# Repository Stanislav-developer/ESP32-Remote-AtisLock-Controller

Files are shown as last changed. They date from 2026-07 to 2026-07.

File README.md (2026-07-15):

<div align="center">

# 🔐 Remote-Door V1.0 <br> Native Ethernet Edition

**Контролер дистанційного керування електромеханічним замком Atis Lock <br> на базі ESP32-C3 + W5500 з нативним стеком lwIP**







Автор: **[Stanislav Turii](https://github.com/Stanislav-developer)** · YouTube: **[@TehnoMaisterna](https://www.youtube.com/@TehnoMaisterna)**

</div>

---

## 🎬 Відеоогляд проєкту

<div align="center">
  <a href="https://youtu.be/d5a214GUi08">
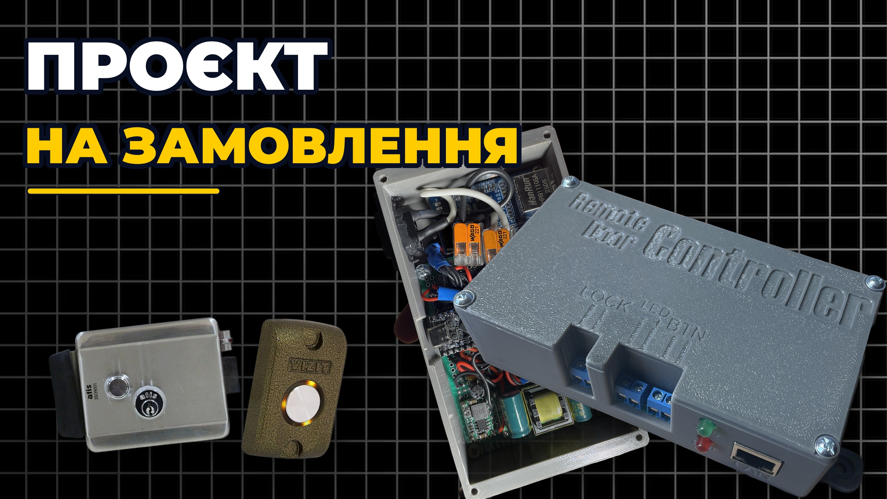
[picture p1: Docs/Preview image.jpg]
Відеоогляд Remote-Door V1.0
    
  </a>
  <p><i>▶️ Натисніть на зображення, щоб переглянути повний відеоогляд збірки та роботи пристрою</i></p>
</div>

---

## 📸 Готовий пристрій

<div align="center">
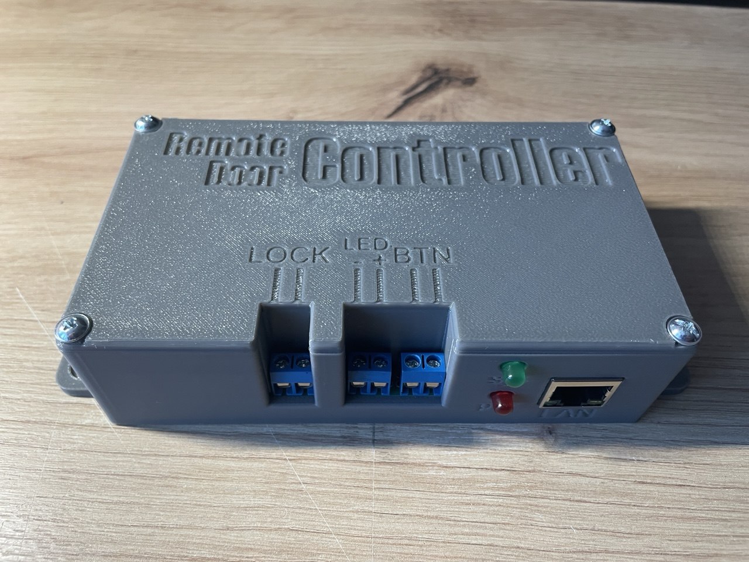
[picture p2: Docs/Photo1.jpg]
Remote-Door Controller — вигляд спереду
  
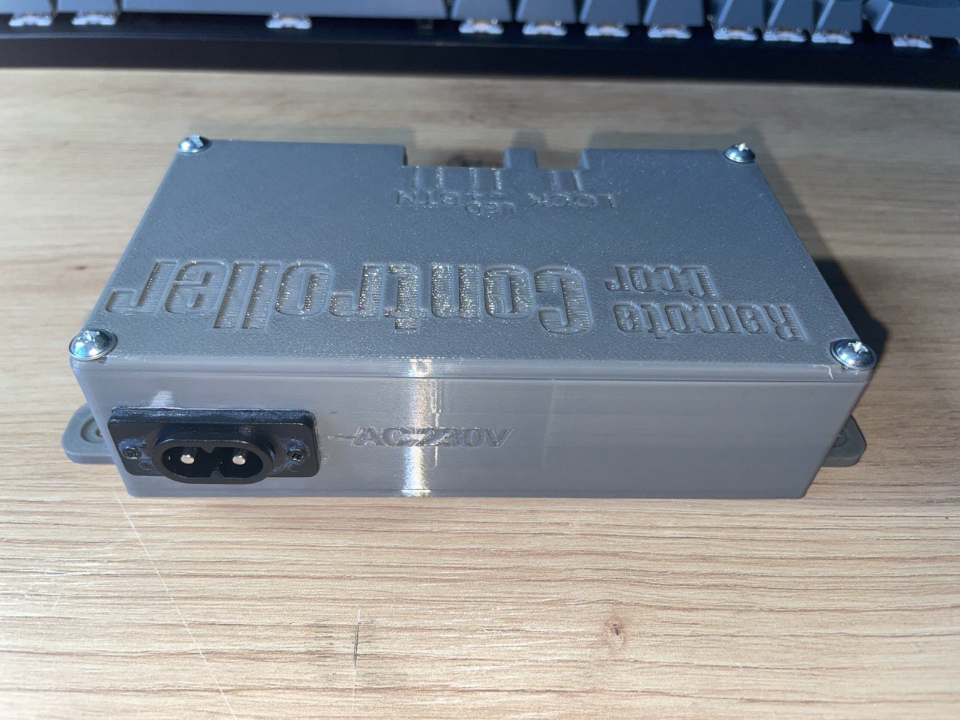
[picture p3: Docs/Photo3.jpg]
Remote-Door Controller — вигляд ззаду з роз'ємом живлення
  
  <br><br>
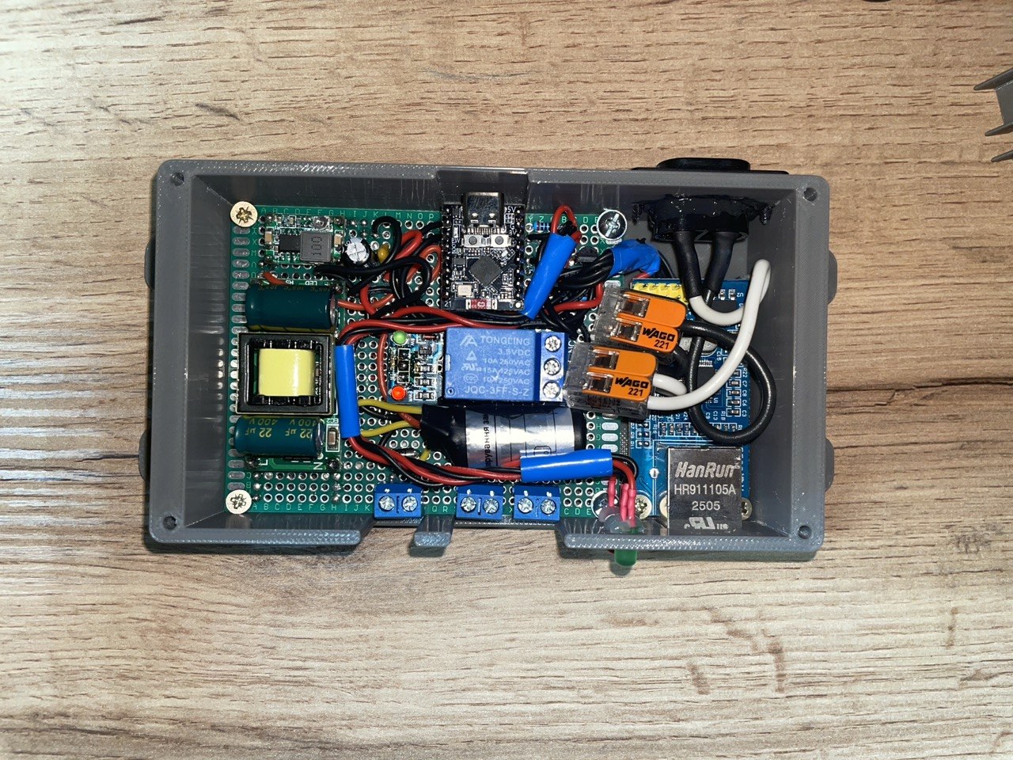
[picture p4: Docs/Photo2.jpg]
Внутрішня компоновка пристрою
  
  <p><i>Корпус надруковано на 3D-принтері. Внутрішня компоновка: AC-DC блок живлення, ESP32-C3, W5500, релейний модуль</i></p>
</div>

---

## 📖 Про проєкт

**Remote-Door** — це автономний контролер для дистанційного або локального керування електромеханічним замком (наприклад, **Atis Lock**) в укриттях, сховищах та об'єктах автоматизації.

Керування здійснюється двома шляхами:

- 🌐 **Дистанційно** — через Telegram-бота з будь-якої точки світу
- 🔘 **Локально** — фізичною антивандальною кнопкою виходу на стіні

Пристрій підключається до мережі **дротовим Ethernet** — жодних проблем з нестабільним Wi-Fi у бетонних укриттях та підвалах.

---

## ⚙️ Архітектура: чому Native Ethernet (ETH.h)?

Ключова особливість проєкту — модуль **W5500 монтується безпосередньо у внутрішній мережевий стек lwIP** операційної системи ESP32 через вбудовану бібліотеку `ETH.h`, а не через сторонні бібліотеки типу `Ethernet.h` чи `EthernetLarge`.

| Критерій | 🟢 Native `ETH.h` (lwIP) | 🔴 Сторонні бібліотеки |
|---|---|---|
| **Швидкість** | Максимальна — драйвер працює на рівні ядра | Програмна емуляція стека, повільніше |
| **DHCP** | Plug & Play, IP отримується автоматично | Часто потрібне ручне налаштування підмереж |
| **TLS / HTTPS** | Апаратне шифрування **mbedtls** — рідний `WiFiClientSecure` працює "з коробки" | Потрібні милиці типу SSLClient |
| **Фаєрволи провайдера** | Стабільне «пробиття» локальних провайдерських фаєрволів | Часті проблеми з NAT/фільтрацією |
| **Сумісність з екосистемою** | Весь код (Telegram, NTP, WebServer) працює як зі звичайним Wi-Fi | Кожна бібліотека вимагає адаптації під свій клієнт |

```cpp
// Монтування W5500 прямо у стек lwIP — одним рядком:
ETH.begin(ETH_PHY_W5500, 1, W5500_CS, -1, W5500_RST, SPI);
```

---

## ✨ Можливості (Features)

- 🤖 **Керування через Telegram** — відкриття замка, дозвіл/заборона кнопки, статус, скидання
- 🔘 **Фізична кнопка виходу** — антивандальна кнопка на стіні з керованою підсвіткою
- ⏳ **Захисний таймаут (Cooldown) 5 секунд** після кожного відкриття:
  - блокує заспамлювання командами з мережі
  - захищає котушку замка від перегріву
  - усуває брязкіт контактів кнопки
  - супроводжується асинхронним миготінням підсвітки кнопки
- 🌐 **Captive Portal конфігурації** — автономна точка доступу з веб-інтерфейсом для налаштування (пароль AP, Bot Token, Chat ID, Group ID). Запускається автоматично при чистій флеш-пам'яті або вручну кнопкою BOOT
- 🔑 **Дворівневе підтвердження безпеки** — команда `/clear_data` вимагає введення системного пароля перед очищенням пам'яті NVS
- 💡 **Асинхронна LED-індикація статусу (SYS LED)**:
  - ⚡ часте блимання — пошук DHCP / очікування мережі
  - 🌊 плавне ШІМ-«дихання» — режим веб-налаштування
  - 🔆 постійне світіння — стабільний зв'язок
- 📊 **Статистика** — лічильник відкривань та аптайм зберігаються у NVS
- 🕐 **Синхронізація часу** через NTP (`pool.ntp.org`, `time.google.com`)

---

## 📦 Специфікація компонентів (BOM)

### Основні модулі

| Фото | Компонент | Опис |
|:---:|---|---|
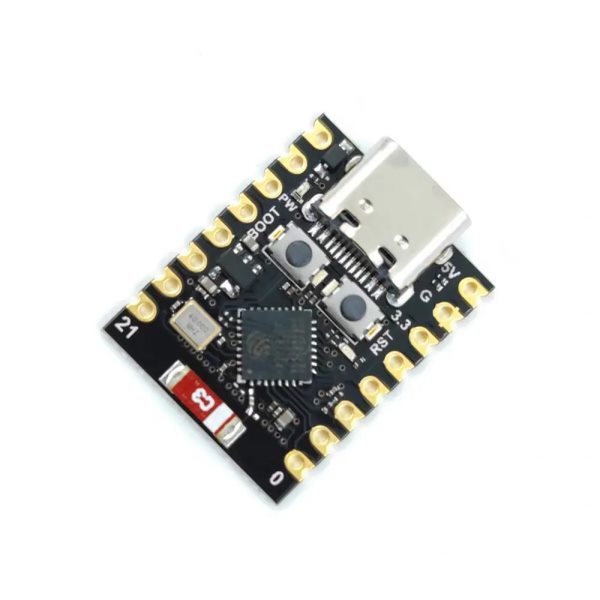
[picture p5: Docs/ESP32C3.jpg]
|  | **ESP32-C3 Super Mini** | Головний мікроконтролер (RISC-V, USB-C) |
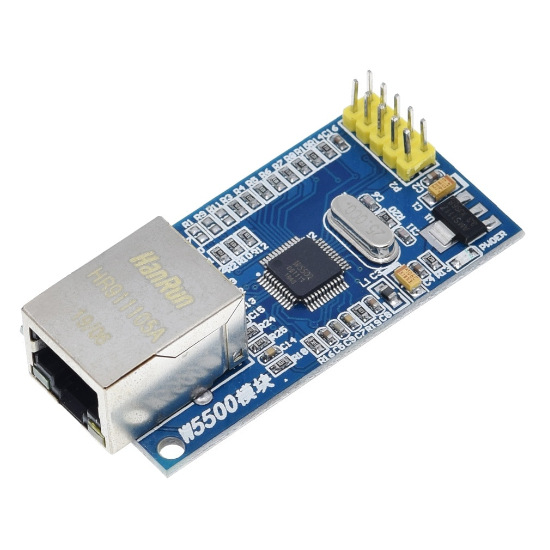
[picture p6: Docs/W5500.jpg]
|  | **W5500 Ethernet Module** | Апаратний TCP/IP контролер, SPI |
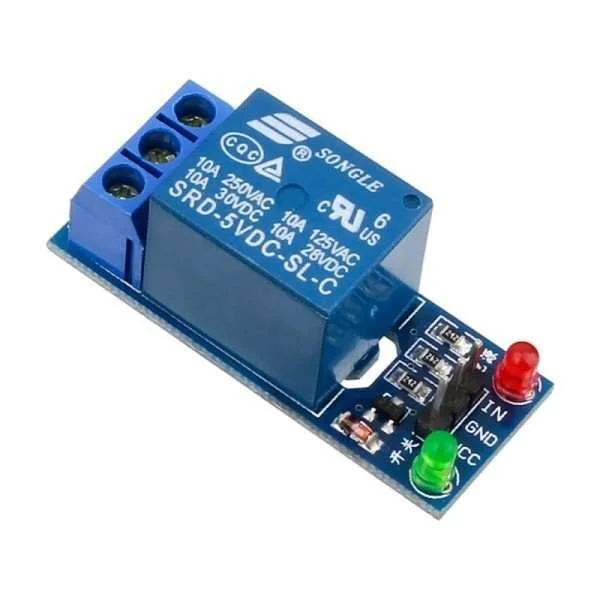
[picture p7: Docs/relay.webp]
|  | **Релейний модуль 5V** | Комутація живлення котушки замка (Active LOW) |
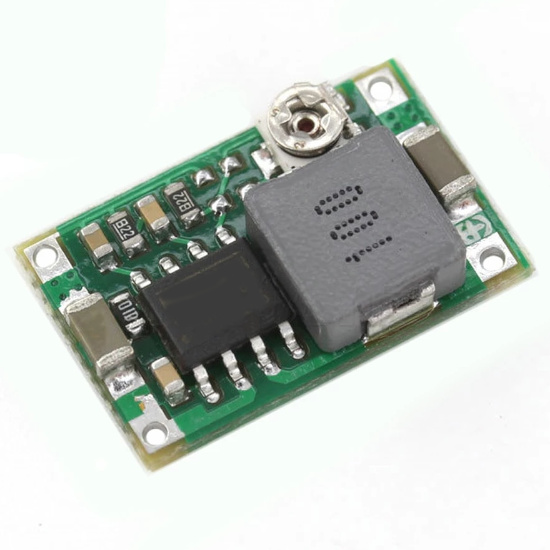
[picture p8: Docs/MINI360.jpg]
|  | **Mini360 (MP2307)** | DC-DC понижуючий конвертер 12V → 5V |
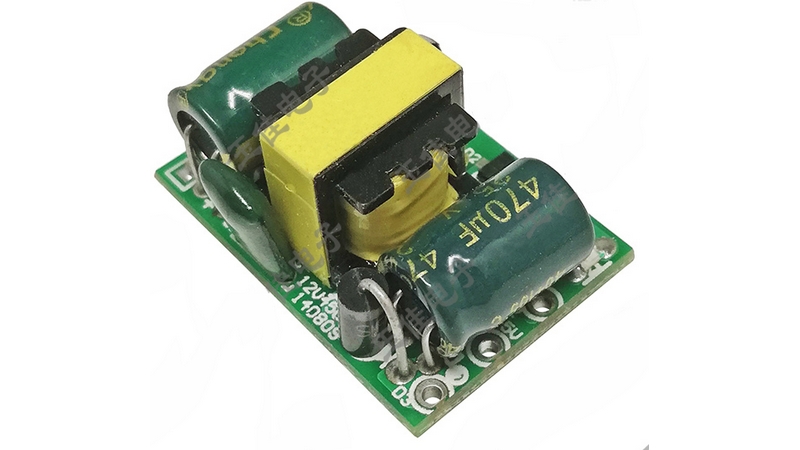
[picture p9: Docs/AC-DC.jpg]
|  | **AC-DC конвертер 220V → 12V, 1A** | Основне джерело живлення пристрою |
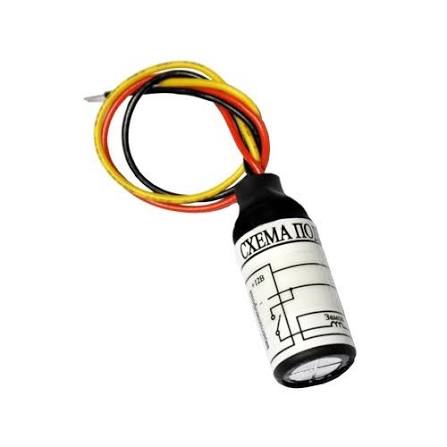
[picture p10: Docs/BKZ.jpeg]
|  | **БКЗ / БУЗ (Блок керування замком)** | Захист котушки замка та фільтрація завад |

### Дискретні компоненти та монтаж

| К-сть | Компонент | Призначення |
|:---:|---|---|
| 1 | Макетна плата **7×9 см** | Несуча плата для монтажу всіх модулів |
| 1 | Електролітичний конденсатор **47 мкФ** | Згладжування просідань живлення |
| 1 | Керамічний конденсатор **100 нФ (0.1 мкФ)** | Фільтрація ВЧ-завад по лінії 5V/GND |
| 2 | Світлодіоди **5 мм** | Індикація системного статусу (sys) та живлення (pwr) |
| 2 | Резистори **330 Ом** | Струмообмеження світлодіодів |
| 1 | Резистор **1.1 кОм** | База транзистора підсвітки кнопки |
| 1 | Резистор **10 кОм** | Підтяжка |
| 1 | Транзистор **BC547 (NPN)** | Ключ підсвітки кнопки виходу |
| 3 | Клеми **DG301-5.0-02P-12-02A** | Підключення замка (LOCK), підсвітки (LED), кнопки (BTN) |
| 1 | Гніздо **AC-006A** | Вхід мережевого живлення 220V |

---

## 🔌 Схема підключення

<div align="center">
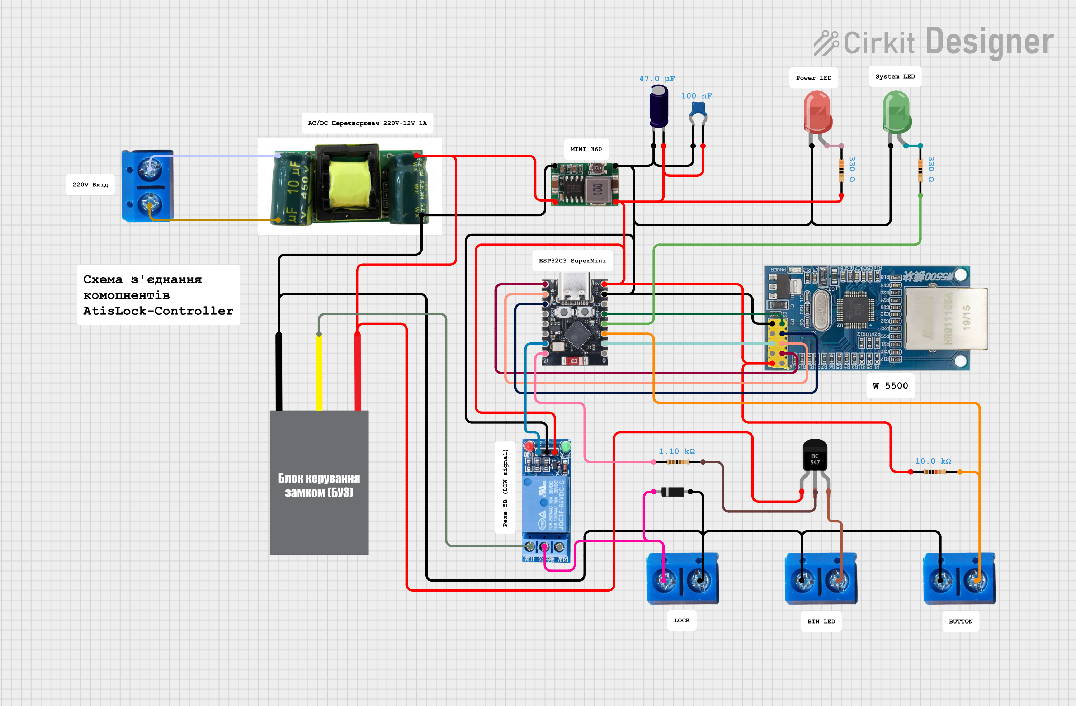
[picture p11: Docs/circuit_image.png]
Принципова схема Remote-Door V1.0
  
  <p><i>Повна схема з'єднань пристрою</i></p>
</div>

### Таблиця розпиновки (Pinout)

**ESP32-C3 ↔ W5500 (SPI):**

| Сигнал W5500 | GPIO ESP32-C3 |
|---|:---:|
| SCK | **4** |
| MISO | **5** |
| MOSI | **6** |
| CS | **7** |
| RST | **1** |

**Периферія:**

| Пристрій | GPIO | Режим |
|---|:---:|---|
| Реле замка | **20** | Active LOW, Z-стан у спокої |
| Транзистор підсвітки кнопки | **21** | Active HIGH |
| Кнопка виходу | **2** | `INPUT_PULLUP`, замикання на GND |
| Системний світлодіод (SYS LED) | **3** | ШІМ (LEDC, 1 кГц) |
| Кнопка BOOT (вхід у режим Setup) | **9** | `INPUT_PULLUP` |

### Транзисторний ключ підсвітки кнопки

Підсвітка реалізована за схемою **Active HIGH** через NPN-транзистор **BC547**:

```
GPIO21 ──[ R 1–1.5 кОм ]──► База BC547
                            Колектор ──► Катод LED кнопки (анод → +живлення)
                            Емітер   ──► GND
```

> [!WARNING]
> **Захист від завад — обов'язковий!** Пристрій працює поруч із силовим обладнанням. Для захисту від високочастотних завад електроінструменту (перфоратори, дрилі) та згладжування мікропросідань логіки живлення **обов'язково** встановіть:
> - **БКЗ (Блок Керування Замком)** у розрив лінії котушки замка
> - Керамічний конденсатор **0.1 мкФ** паралельно лініям живлення 5V/GND плат
> - Захисний діод **1N4007** на котушці замка (зворотним ввімкненням)
>
> Без цих елементів можливі хибні перезавантаження ESP32 у момент роботи замка.

> [!NOTE]
> Реле керується нестандартно, але безпечно: у стані спокою GPIO20 переведено у **високоімпедансний Z-стан** (`INPUT`), а для спрацювання пін короткочасно стає виходом із низьким рівнем. Це виключає випадкове відкриття замка при старті/перезавантаженні контролера.

---

## 🖨️ 3D-модель корпуса

Корпус розроблено у **Fusion 360** та надруковано на 3D-принтері. Кришка має гравіювання назви пристрою та маркування всіх клем (LOCK / LED / BTN), а бічні панелі — вирізи під RJ45, індикатори та гніздо живлення 230V.

<div align="center">
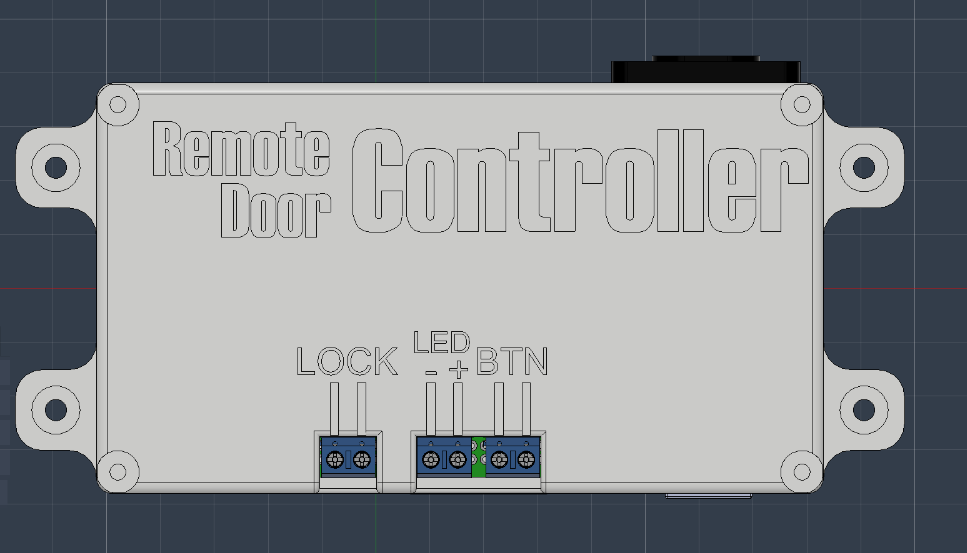
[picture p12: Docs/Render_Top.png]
Рендер верхньої кришки з маркуванням клем
  
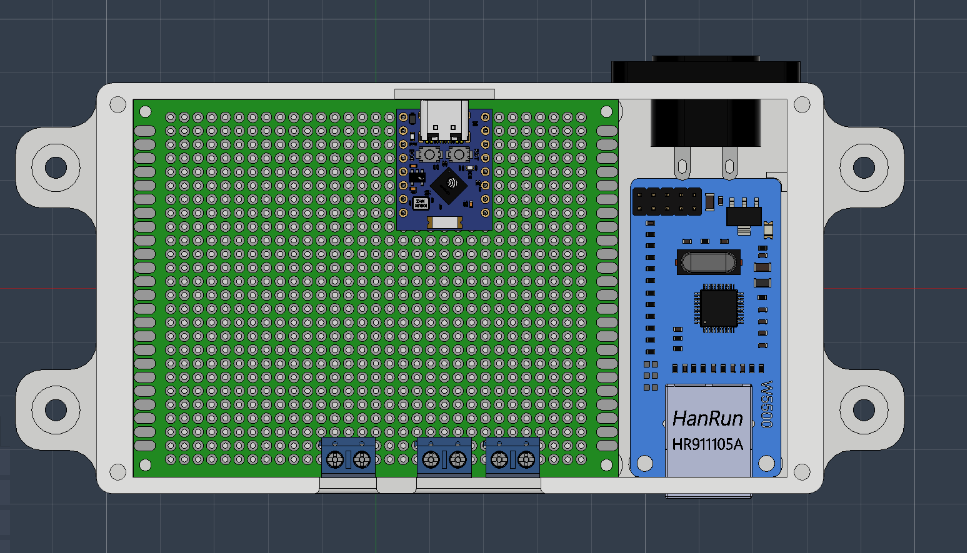
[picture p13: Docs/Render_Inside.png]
Рендер внутрішньої компоновки
  
  <br><br>
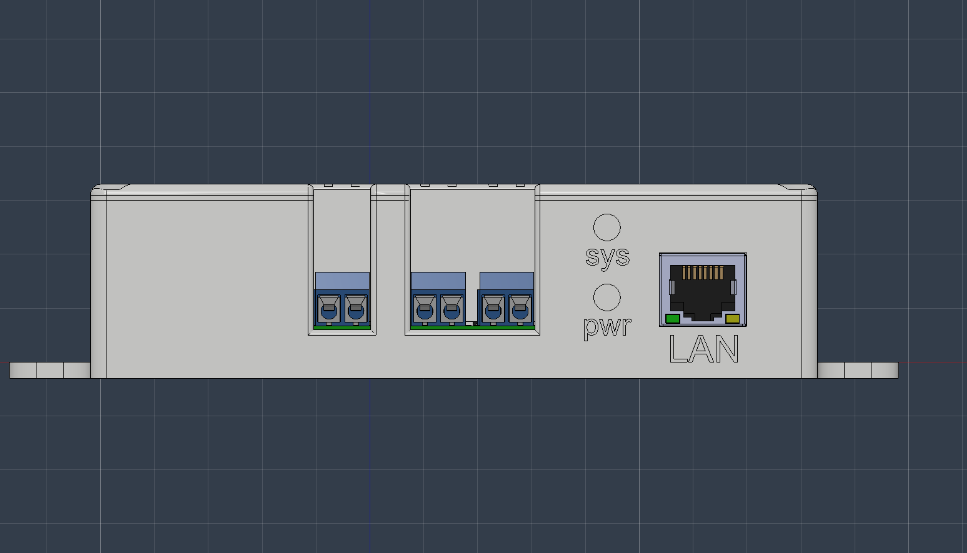
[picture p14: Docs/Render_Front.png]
Рендер передньої панелі: клеми, індикатори sys/pwr, LAN
  
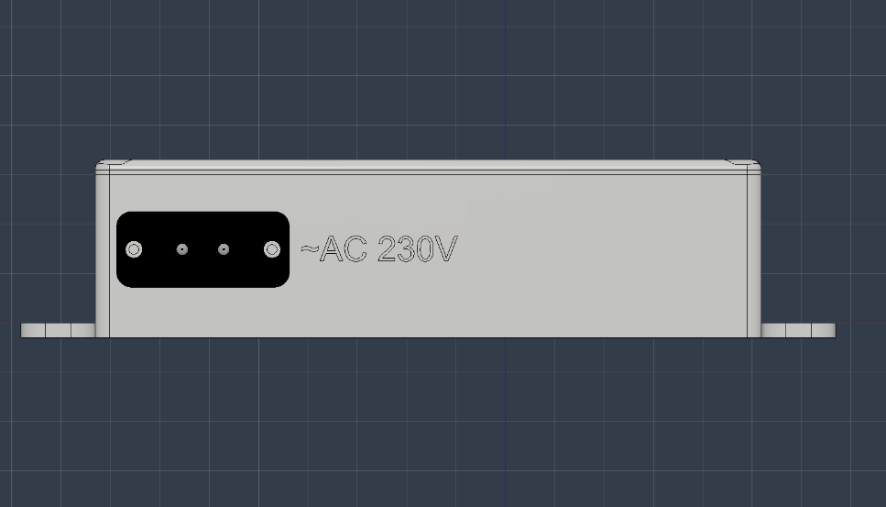
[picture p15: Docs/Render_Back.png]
Рендер задньої панелі: гніздо AC 230V
  
</div>

### 📥 Завантажити файли для друку

| Файл | Опис |
|---|---|
| [**Top.stl**](3D%20Models/Top.stl) | Верхня кришка з гравіюванням та отворами під клеми |
| [**Bottom.stl**](3D%20Models/Bottom.stl) | Основа корпуса з монтажними вушками |

> [!TIP]
> Рекомендовані налаштування друку: PETG або ABS (пристрій може працювати у неопалюваних приміщеннях), заповнення 15–20%, шар 0.2 мм.

---

## 🚀 Перший запуск та конфігурація

### Крок 1 — Прошивка

Налаштування **Arduino IDE** (меню *Tools*):

| Параметр | Значення |
|---|---|
| Board | `ESP32C3 Dev Module` |
| **USB CDC On Boot** | `Enabled` ⚠️ *(обов'язково для Serial Monitor)* |
| **Partition Scheme** | `Huge APP (3MB No OTA/1MB SPIFFS)` |
| Решта налаштувань | за замовчуванням |

Необхідна бібліотека: [`UniversalTelegramBot`](https://github.com/witnessmenow/Universal-Arduino-Telegram-Bot) (встановлюється через Library Manager).

**Вхід у режим прошивки (bootloader):**
1. Під'єднайте ESP32-C3 до комп'ютера через USB-C
2. Затисніть кнопку **BOOT**
3. Утримуючи BOOT, натисніть **RESET** (~1 сек)
4. Відпустіть RESET, потім відпустіть BOOT

### Крок 2 — Створення Telegram-бота

1. Напишіть [@BotFather](https://t.me/BotFather) → `/newbot` → отримайте **Bot Token**
2. Дізнайтеся свій **Chat ID** (наприклад, через [@userinfobot](https://t.me/userinfobot))
3. *(Опційно)* Додайте бота у групу та отримайте її **Group ID**

### Крок 3 — Налаштування через Web-інтерфейс

1. При **першому запуску** (чиста флеш-пам'ять) пристрій автоматично створює точку доступу **`Remote-Door-Setup`**. Системний світлодіод плавно «дихає» 🌊
2. Підключіться до цієї Wi-Fi мережі з телефона — Captive Portal відкриє сторінку налаштувань автоматично (або перейдіть на `192.168.4.1`)
3. Заповніть поля:
   - **Системний пароль** (мін. 8 символів) — захищає точку доступу та команду скидання
   - **Telegram Bot Token**
   - **Chat ID власника**
   - **Group ID** *(необов'язково)*
4. Натисніть **ЗБЕРЕГТИ** — пристрій перезавантажиться та підключиться до мережі

> [!TIP]
> Щоб **повторно увійти в режим налаштування** на вже сконфігурованому пристрої — затисніть кнопку **BOOT (GPIO9)** та увімкніть живлення (або натисніть RESET, утримуючи BOOT).

### Крок 4 — Підключення Ethernet

Вставте кабель у роз'єм RJ45 (LAN). Пристрій отримає IP через **DHCP** автоматично — жодних ручних налаштувань. Після успішного підключення:
- системний LED (sys) світиться **постійно** 🔆
- у Telegram надходить повідомлення *«Контролер Remote-Door активний!»*

---

## 🤖 Команди Telegram-бота

| Команда | Дія |
|---|---|
| `/unlock` | 🔓 Відчинити двері *(прихована з публічного меню)* |
| `/allow` | ✅ Дозволити відкриття з фізичної кнопки |
| `/deny` | 🚫 Заборонити відкриття з фізичної кнопки |
| `/status` | 📊 Статус системи, лічильник відкривань, аптайм |
| `/clear_data` | ⚠️ Повне скидання конфігурації *(вимагає пароль)* |
| `/help`, `/start` | 👋 Довідка |

### Список для швидкої вставки у BotFather (`/setcommands`)

```
allow - Дозволити відкриття дверей з фізичної кнопки
deny - Заборонити відкриття дверей з фізичної кнопки
status - Отримати статус системи та час аптайму
clear_data - Повне скидання конфігурації та статистики
```

> [!NOTE]
> Команда `/unlock` **свідомо не додається** у публічне меню бота — вона працює, але не світиться у списку команд. Це додатковий рівень захисту від випадкового натискання.

---

## 📁 Структура репозиторію

```
ESP32-Remote-AtisLock-Controller/
├── 3D Models/
│   ├── Top.stl                  # Верхня кришка корпуса
│   └── Bottom.stl               # Основа корпуса
├── Docs/                        # Фото, схема, рендери для README
├── Remote_Door_V1.0/
│   └── Remote_Door_V1.0.ino    # Прошивка
├── LICENSE                      # MIT
└── README.md
```

---

## 📜 Ліцензія

Проєкт розповсюджується за ліцензією **[MIT](LICENSE)** — використовуйте, модифікуйте та діліться вільно.

---

<div align="center">

**Developed with ❤️ by [Stanislav Turii](https://github.com/Stanislav-developer)**

🎥 [YouTube — TehnoMaisterna](https://www.youtube.com/@TehnoMaisterna) · 💻 [GitHub](https://github.com/Stanislav-developer)

⭐ *Якщо проєкт був корисним — поставте зірку репозиторію!*

</div>

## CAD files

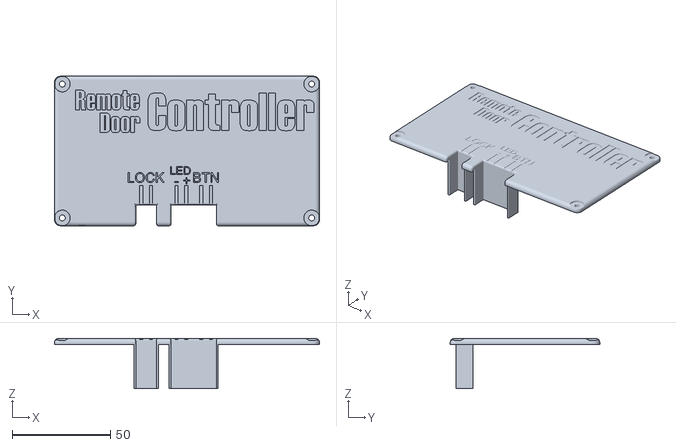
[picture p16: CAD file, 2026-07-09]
3D Models/Top.stl
135.0 x 76.2 x 25.5

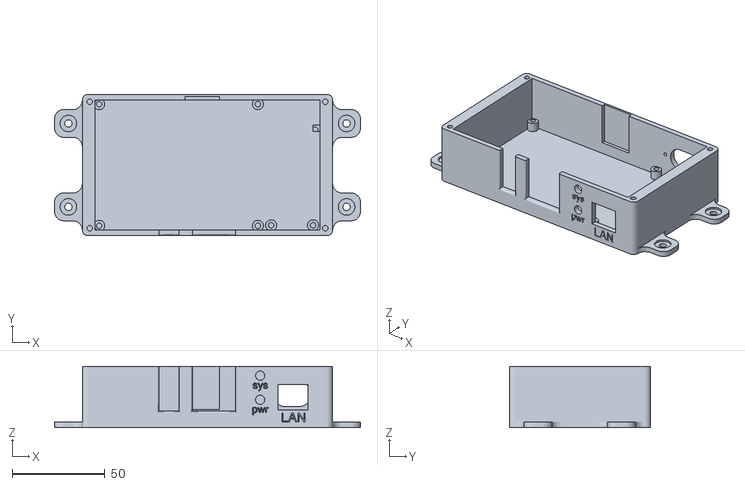
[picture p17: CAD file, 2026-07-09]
3D Models/Bottom.stl
165.0 x 76.2 x 33.0

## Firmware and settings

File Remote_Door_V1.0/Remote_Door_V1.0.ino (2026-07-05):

/* Remote-Door firmware V1.0
Repository: https://github.com/Stanislav-developer/ESP32-Remote-AtisLock-Controller
Author: Stanislav Turii (GitHub: https://github.com/Stanislav-developer || Youtube: https://www.youtube.com/@TehnoMaisterna)
Date: 2026.05.23

НАЛАШТУВАННЯ ДЛЯ ЗАЛИВКИ ПРОШИВКИ (ESP32-C3):
У Tools:
1. Board: "ESP32C3 Dev Module"
2. USB CDC On Boot: "Enabled" (Обов'язково для Serial Monitor)
3. Решта налаштувань: за замовчуванням

ЯК УВІЙТИ В РЕЖИМ ПРОШИВКИ:
1. Під'єднайте ESP32 до комп'ютера.
2. Затисніть кнопку BOOT.
3. Утримуючи BOOT, натисніть кнопку RESET (1 сек).
4. Відпустіть RESET, а потім відпустіть BOOT.
*/

// Підключення вбудованих бібліотек ядра ESP32
#include <ETH.h> // Для роботи з Ethernet залізом на рівні ядра
#include <SPI.h> // Для зв'язку з W5500 по SPI шині
#include <WiFi.h> // Потрібна для підняття власної точки доступу (AP)
#include <WiFiClientSecure.h> // Нативний захищений SSL клієнт
#include <WebServer.h> // Для роботи веб-сервера конфігурації
#include <DNSServer.h> // Для перенаправлення трафіку (Captive Portal)
#include <Preferences.h> // Для роботи з енергонезалежною пам'яттю
#include <UniversalTelegramBot.h> // Бібліотека Telegram API

// Конфігурація апаратних пінів (ESP32-C3 Super Mini)
#define RELAY_PIN 20     // Керування силовим реле замка (Активний низький)
#define LED_BTN_PIN 21   // Транзистор підсвітки кнопки (Активний високий)
#define BUTTON_PIN 2     // Домофонна кнопка виходу на стіні (INPUT_PULLUP)
#define LED_SYS_PIN 3    // Системний світлодіод індикації статусу (ШІМ сумісний)

// Апаратні піни SPI шини та скидання для Ethernet контролера W5500
#define W5500_SCK 4
#define W5500_MISO 5
#define W5500_MOSI 6
#define W5500_CS 7
#define W5500_RST 1

// Дані конфігурації системи (заповнюються через Веб-Інтерфейс або Preferences)
String apPassword = "";  // Пароль для точки доступу та скидання налаштувань
String botToken = "";    // API Токен Telegram бота
String chatId = "";      // Чат ID адміна (власника системи)
String groupId = "";     // Чат ID робочої групи або каналу

// Об'єкти системних класів
Preferences preferences; // Об'єкт для збереження конфігурації в NVS флеш
WiFiClientSecure client; // Безпечний клієнт із підтримкою апаратного mbedtls
UniversalTelegramBot bot(botToken, client); // Об'єкт обробника Telegram API
WebServer server(80);     // Веб-сервер на стандартному 80 порту
DNSServer dnsServer;     // DNS сервер для реалізації Captive Portal

// --- ГЛОБАЛЬНІ ЗМІННІ СТАНУ ---
bool isAccessAllowed = false; // Дозвіл на відкриття дверей з фізичної кнопки
int openCount = 0;            // Загальна кількість відкривань замка за весь час

// Змінні для асинхронного керування системним світлодіодом (без затримок delay)
unsigned long lastSysLedBlink = 0; // Таймер останнього перемикання стану LED
bool sysLedState = false;          // Поточний стан світлодіода (вкл/викл)
int sysLedInterval = 300; // Інтервал блимання: 300мс - пошук мережі, 1500мс - помилка, 0 - норма

// Змінні захисного таймауту кнопки та реле (блокування від заспамлювання)
bool isButtonCooldown = false;     // Прапорець активного режиму блокування
unsigned long cooldownStartTime = 0; // Час початку таймауту безпеки
unsigned long lastBtnLedToggle = 0; // Таймер миготіння підсвітки кнопки
bool btnLedState = false;          // Поточний стан підсвітки кнопки виходу
const unsigned long COOLDOWN_DURATION = 5000; // Тривалість блокування (5 секунд)

// Змінні авторизації для процедури очищення пам'яті через чат
bool waitingForClearDataPass = false; // Очікування введення пароля в чат
String clearDataRequesterId = "";     // ID користувача, який затребував очищення

// Глобальний прапор успішного підключення Ethernet на рівні lwIP стеку
bool eth_connected = false;

// HTML код розмітки сторінки конфігурації Веб-Інтерфейсу
const char index_html[] PROGMEM = R"rawliteral(
<!DOCTYPE HTML><html><head>
  <title>Remote-Door Setup</title>
  <meta charset="UTF-8">
  <meta name="viewport" content="width=device-width, initial-scale=1">
  <style>
    body { font-family: Arial, sans-serif; background-color: #0b132b; color: #ffffff; text-align: center; margin: 0; }
    .header { background-color: #1c2541; padding: 20px; border-bottom: 3px solid #3a506b; }
    .container { padding: 20px; max-width: 400px; margin: 0 auto; background-color: #1c2541; border-radius: 8px; margin-top: 20px; }
    input { width: 100%; padding: 12px; margin: 8px 0; box-sizing: border-box; background-color: #0b132b; color: #fff; border: 2px solid #3a506b; border-radius: 4px; }
    input[type=submit] { background-color: #3a506b; color: white; border: none; cursor: pointer; font-weight: bold; font-size: 16px; margin-top: 10px; }
    input[type=submit]:hover { background-color: #5bc0be; color: #0b132b; }
    .footer { margin-top: 30px; font-size: 12px; color: #aaa; border-top: 1px solid #3a506b; padding-top: 15px; }
    a { color: #5bc0be; text-decoration: none; display: block; margin-bottom: 10px; }
  </style>
</head><body>
  <div class="header"><h1>Remote-Door V1.0 (Ethernet)</h1></div>
  <div class="container">
    <h3>Налаштування пристрою</h3>
    <form action="/save" method="POST">
      <label>Системний пароль (для AP та скидання)</label><input type="text" name="ap_pass" placeholder="Мінімум 8 символів">
      <label>Telegram Bot Token</label><input type="text" name="token" placeholder="Токен бота">
      <label>Власник (Chat ID)</label><input type="text" name="owner" placeholder="ID власника">
      <label>Група (Group ID)</label><input type="text" name="group" placeholder="ID групи (необов'язково)">
      <input type="submit" value="ЗБЕРЕГТИ">
    </form>
    <div class="footer">
      <h4>Developed by Stanislav Turii</h4>
      <a href='https://github.com/Stanislav-developer'>GitHub Repository</a>
    </div>
  </div>
</body></html>)rawliteral";

// Функція відображення головної сторінки сервера
void handleRoot() {
  server.send(200, "text/html; charset=utf-8", index_html);
}

// Функція валідації та збереження отриманих даних у Preferences
void handleSave() {
  if (server.hasArg("token") && server.hasArg("owner") && server.hasArg("ap_pass")) {
    String n_token = server.arg("token");
    String n_owner = server.arg("owner");
    String n_group = server.arg("group");
    String n_ap_pass = server.arg("ap_pass");

    if (n_ap_pass.length() >= 8) {
      preferences.putString("token", n_token);
      preferences.putString("chatId", n_owner);
      preferences.putString("groupId", n_group);
      preferences.putString("apPass", n_ap_pass);

      String response = "<html><head><meta charset='utf-8'></head><body style='background-color:#0b132b; color:white; text-align:center; font-family:Arial;'>";
      response += "<h1 style='color:#5bc0be;'>Збережено! ✅</h1><p>Перезавантаження...</p></body></html>";
      server.send(200, "text/html; charset=utf-8", response);
      
      delay(2000);
      ESP.restart(); // Перезапуск для застосування конфігурації
    } else {
      server.send(400, "text/plain; charset=utf-8", "Помилка: Системний пароль має бути мінімум 8 символів!");
      return;
    }
  } else {
    server.send(400, "text/plain; charset=utf-8", "Error: Missing data");
  }
}

// Функція ініціалізації аварійної точки доступу та вічного циклу Веб-сервера
void launchWebServer() {
    WiFi.mode(WIFI_AP);
    if (apPassword.length() >= 8 && apPassword != "1") {
      WiFi.softAP("Remote-Door-Setup", apPassword.c_str());
    } else {
      WiFi.softAP("Remote-Door-Setup");
    }
    
    dnsServer.start(53, "*", WiFi.softAPIP());
    server.on("/", handleRoot);
    server.on("/save", handleSave);
    server.onNotFound(handleRoot);
    server.begin();
    
    Serial.println("[DEBUG] Точка доступу створена. IP: " + WiFi.softAPIP().toString());

    int fadeValue = 0;
    int fadeDirection = 5;
    unsigned long lastFadeTime = 0;

    // Вічний ізольований цикл обробки веб-запитів із плавним ШІМ ефектом для системного LED
    while (true) {
      dnsServer.processNextRequest();
      server.handleClient();
      
      if (millis() - lastFadeTime > 25) {
        lastFadeTime = millis();
        fadeValue += fadeDirection;
        if (fadeValue <= 0 || fadeValue >= 255) {
          fadeDirection = -fadeDirection; 
        }
        ledcWrite(LED_SYS_PIN, fadeValue);
      }
    }
}

// Конвертація лічильника секунд аптайму у текстовий формат (дні, години, хвилини)
String formatDuration(unsigned long seconds) {
  unsigned long days = seconds / 86400;
  unsigned long hours = (seconds % 86400) / 3600;
  unsigned long minutes = (seconds % 3600) / 60;
  unsigned long secs = seconds % 60;
  String result = "";
  if (days > 0) result += String(days) + " д. ";
  if (hours > 0 || days > 0) result += String(hours) + " год. ";
  if (minutes > 0 || hours > 0 || days > 0) result += String(minutes) + " хв. ";
  result += String(secs) + " сек.";
  return result;
}

// Функція генерації низькорівневого імпульсу на реле для відкриття замка
void openDoor() {
  digitalWrite(RELAY_PIN, LOW);   // Гарантуємо низький рівень (увімкнення реле)
  pinMode(RELAY_PIN, OUTPUT);     // Перемикаємо на вихід для подачі землі на реле
  delay(1000);                    // Утримання імпульсу 1 секунду (стандарт контролерів)
  pinMode(RELAY_PIN, INPUT);      // Переводимо у високоімпедансний стан (відпускаємо реле)
  
  openCount++;
  preferences.putInt("openCount", openCount);
  Serial.println("[DEBUG] Двері фізично відчинено (імпульс реле завершено).");
}

// Функція розбору та маршрутизації команд, що прийшли через мережу з серверів Telegram
void handleNewMessages() {
  String chat_id = String(bot.messages[0].chat_id);
  String text = bot.messages[0].text;
  String from_name = bot.messages[0].from_name;
  
  if (chat_id == chatId || chat_id == groupId) {
    
    // КРИТИЧНИЙ ЗАХИСТ: Ігноруємо порожні текстові об'єкти (медіафайли, стікери), запобігаючи паніці ядра
    if (text.length() == 0) return;

    // Очищення та нормалізація синтаксису команд (відрізання аргументів та тегів бота)
    String cmd = text;
    int spaceIdx = cmd.indexOf(' ');
    if (spaceIdx != -1) cmd = cmd.substring(0, spaceIdx); 
    int atIdx = cmd.indexOf('@');
    if (atIdx != -1) cmd = cmd.substring(0, atIdx);       

    // Обробка введення пароля для підтвердження процедури повного очищення флеш-пам'яті
    if (waitingForClearDataPass && chat_id == clearDataRequesterId) {
        if (text == apPassword && apPassword.length() > 0) {
            Serial.println("[DEBUG] Користувач [" + from_name + "] ввів ПРАВИЛЬНИЙ пароль. Очищення пам'яті NVS та рестарт.");
            preferences.clear();
            preferences.putString("token", "1");
            preferences.putString("chatId", "1");
            preferences.putString("groupId", "1");
            preferences.putString("apPass", "1");
            
            bot.sendMessage(chat_id, "⚠️ Дані очищені. Перезапуск у режим конфігурації...", "");
            delay(1000);
            ESP.restart(); 
        } else {
            Serial.println("[DEBUG] Користувач [" + from_name + "] ввів НЕВІРНИЙ пароль для очищення даних. Скасовано.");
            bot.sendMessage(chat_id, "❌ Невірний пароль. Операцію скасовано.", "");
            waitingForClearDataPass = false;
        }
        return; 
    }

    // Команда дистанційного відкриття дверей
    if (cmd == "/unlock") {
      if (isButtonCooldown) {
        unsigned long remaining = (COOLDOWN_DURATION - (millis() - cooldownStartTime)) / 1000;
        if (remaining == 0) remaining = 1;
        
        Serial.println("[DEBUG] Користувач [" + from_name + "] викликав /unlock під час таймауту. ВІДХИЛЕНО. Залишилось: " + String(remaining) + "с.");
        bot.sendMessage(chat_id, "⏳ <b>Зачекайте!</b> Замок щойно відчинявся. Тайм-аут: " + String(remaining) + " сек.", "HTML");
      } else {
        Serial.println("[DEBUG] Користувач [" + from_name + "] викликав /unlock. Виконую відкриття дверей...");
        bot.sendMessage(chat_id, "🔓 Користувач <b>" + from_name + "</b> відчинив двері.", "HTML");
        
        openDoor(); 
        
        isButtonCooldown = true;
        cooldownStartTime = millis(); // Старт таймауту безпеки строго після закриття реле
      }
    }
    
    // Команда активації локальної кнопки виходу
    else if (cmd == "/allow") {
      Serial.println("[DEBUG] Користувач [" + from_name + "] надіслав /allow. Доступ з кнопки дозволено.");
      isAccessAllowed = true;
      if (!isButtonCooldown) digitalWrite(LED_BTN_PIN, HIGH); 
      bot.sendMessage(chat_id, "✅ Користувач <b>" + from_name + "</b> ДОЗВОЛИВ відкриття дверей з кнопки.", "HTML");
    }
    
    // Команда повної деактивації локальної кнопки виходу
    else if (cmd == "/deny") {
      Serial.println("[DEBUG] Користувач [" + from_name + "] надіслав /deny. Доступ з кнопки ЗАБОРОНЕНО.");
      isAccessAllowed = false;
      digitalWrite(LED_BTN_PIN, LOW); 
      bot.sendMessage(chat_id, "🚫 Користувач <b>" + from_name + "</b> ЗАБОРОНИВ відкриття дверей з кнопки.", "HTML");
    }
    
    // Команда телеметрії та діагностики аптайму системи
    else if (cmd == "/status") {
      Serial.println("[DEBUG] Користувач [" + from_name + "] запитав статус системи за командою /status.");
      String status_message = "📊 <b>Статус Remote-Door:</b>\n\n";
      status_message += "Стан доступу: ";
      status_message += isAccessAllowed ? "🟢 Дозволено\n" : "🔴 Заборонено\n";
      status_message += "Кількість відкривань: <b>" + String(openCount) + "</b>\n";
      unsigned long uptime = millis() / 1000;
      status_message += "Пристрій працює: " + formatDuration(uptime);
      bot.sendMessage(chat_id, status_message, "HTML");
    }
    
    // Запит на повне скидання конфігураційних параметрів контролера
    else if (cmd == "/clear_data") {
      Serial.println("[DEBUG] Користувач [" + from_name + "] ініціював команду /clear_data. Очікування підтвердження паролем.");
      waitingForClearDataPass = true;
      clearDataRequesterId = chat_id;
      bot.sendMessage(chat_id, "⚠️ <b>УВАГА!</b> Ви дійсно бажаєте стерти всі дані та статистику?\n\nНадішліть ваш <b>системний пароль</b> для підтвердження або будь-яний інший текст для скасування.", "HTML");
    }
    
    // Команди виведення інформаційного меню довідки
    else if (cmd == "/help" || cmd == "/start") {
      Serial.println("[DEBUG] Користувач [" + from_name + "] викликав довідку за командою " + cmd);
      String help_message = "👋 Привіт, " + from_name + "!\n\n";
      help_message += "Доступні команди:\n";
      help_message += "/unlock - Відкрити двері\n";
      help_message += "/allow - Дозволити доступ з кнопки\n";
      help_message += "/deny - Заборонити доступ з кнопки\n";
      help_message += "/status - Стан системи\n";
      help_message += "/clear_data - Скидання до заводських\n";
      bot.sendMessage(chat_id, help_message, "");
    }
  }
}

// Перехоплювач системних подій Ethernet драйвера ядра (lwIP стек)
void WiFiEvent(WiFiEvent_t event) {
  switch (event) {
    case ARDUINO_EVENT_ETH_START:
      Serial.println("[DEBUG] Нативний драйвер ETH запущено.");
      break;
    case ARDUINO_EVENT_ETH_CONNECTED:
      Serial.println("[DEBUG] Кабель Ethernet підключено (Фізичний лінк OK) ✅");
      break;
    case ARDUINO_EVENT_ETH_GOT_IP:
      Serial.print("[DEBUG] Роутер видав IP адресу: ");
      Serial.println(ETH.localIP());
      eth_connected = true;
      sysLedInterval = 0; // Постійне стабільне світіння — мережа наявна
      break;
    case ARDUINO_EVENT_ETH_DISCONNECTED:
      Serial.println("[WARNING] Кабель Ethernet відключено!");
      eth_connected = false;
      sysLedInterval = 300; // Повертаємо режим швидкого блимання (пошук мережі)
      break;
    case ARDUINO_EVENT_ETH_STOP:
      Serial.println("[DEBUG] Драйвер ETH зупинено.");
      eth_connected = false;
      break;
    default:
      break;
  }
}

// Функція первинної апаратної ініціалізації периферії (виконується одноразово)
void setup() {
  Serial.begin(115200);
  delay(1000);
  Serial.println("\n\n========================================");
  Serial.println("[DEBUG] Запуск системи Remote-Door V1.0 (Native ETH)");
  Serial.println("========================================");

  // Налаштування режимів роботи GPIO виводів
  pinMode(RELAY_PIN, INPUT); // За замовчуванням Z-стан (безпека від випадкових спрацювань замка)
  pinMode(LED_BTN_PIN, OUTPUT);
  digitalWrite(LED_BTN_PIN, LOW); 
  pinMode(BUTTON_PIN, INPUT_PULLUP);
  pinMode(9, INPUT_PULLUP); // Кнопка Boot для виходу в режим Веб-сервера вручну

  // Конфігурація апаратних таймерів ШІМ двигуна (LEDC драйвер) під нове ядро Core v3.x
  ledcAttach(LED_SYS_PIN, 1000, 8); // Частота 1 кГц, розрядність 8 біт (0-255)
  ledcWrite(LED_SYS_PIN, 0); 

  preferences.begin("remote-door", false); // Відкриваємо простір імен preferences

  // Аварійний запуск конфігуратора при апаратному утриманні кнопки BOOT при старті
  if (digitalRead(9) == LOW) {
    launchWebServer();
  }

  // Читання параметрів конфігурації з енергонезалежної пам'яті
  botToken = preferences.getString("token", botToken);
  chatId = preferences.getString("chatId", chatId);
  groupId = preferences.getString("groupId", groupId);
  apPassword = preferences.getString("apPass", apPassword);
  openCount = preferences.getInt("openCount", 0);

  // Перевірка наявності валідних даних; якщо флеш чистий — запуск конфігуратора
  if (botToken == "1" || botToken == "") {
    launchWebServer();
  }

  WiFi.onEvent(WiFiEvent); // Реєстрація ядра для відстеження подій кабелю

  // Апаратний цикл скидання Ethernet контролера W5500 для стабілізації заліза
  Serial.println("[DEBUG] Виконую апаратне скидання W5500...");
  pinMode(W5500_RST, OUTPUT);
  digitalWrite(W5500_RST, LOW);
  delay(100);
  digitalWrite(W5500_RST, HIGH);
  delay(500); 

  // Ініціалізація шини SPI (передаємо -1 для CS, оскільки ним автоматично керує ETH.h)
  SPI.begin(W5500_SCK, W5500_MISO, W5500_MOSI, -1);

  // Інтеграція інтерфейсу W5500 безпосередньо у внутрішній стек lwIP ядра операційної системи
  Serial.println("[DEBUG] Монтування чипа W5500 у систему...");
  if (!ETH.begin(ETH_PHY_W5500, 1, W5500_CS, -1, W5500_RST, SPI)) {
    Serial.println("[ERROR] Помилка монтування W5500!");
    sysLedInterval = 300;
  }

  // Network initialization connection timeout safety loop
  unsigned long startOrder = millis();
  while (!eth_connected && millis() - startOrder < 15000) {
    if (millis() - lastSysLedBlink > 300) {
      lastSysLedBlink = millis();
      sysLedState = !sysLedState;
      ledcWrite(LED_SYS_PIN, sysLedState ? 255 : 0);
    }
    delay(10);
  }

  // Конфігурація та оптимізація таймаутів нативного клієнта TLS (mbedtls)
  client.setTimeout(3000); // Запобігає тривалому блокуванню сторожового таймера (Watchdog)
  client.setInsecure();    // Використовуємо спрощене SSL рукостискання (без локального парсингу сертифікатів)
  bot.updateToken(botToken);

  // Ініціалізація та синхронізація системного годинника через мережеві сервери часу
  configTime(0, 0, "pool.ntp.org", "time.google.com");

  if (eth_connected) {
    String startMessage = "🔐 <b>Контролер Remote-Door активний!</b>\n";
    startMessage += "Версія: V1.0 | Підключено успішно.";
    
    Serial.println("[DEBUG] Спроба відправити повідомлення через нативний стек...");
    if (bot.sendMessage(chatId, startMessage, "HTML")) {
      Serial.println("[DEBUG] Повідомлення надіслано успішно! ✅");
      sysLedInterval = 0; 
    } else {
      Serial.println("[ERROR] Помилка відправки. Перехід у Web-Setup.");
      sysLedInterval = 1500; 
      delay(2000); 
      launchWebServer(); 
    }
  }

  // Очищення черги старих запитів для запобігання хибних спрацювань замка після увімкнення
  int newMessage = bot.getUpdates(-1);
  if (newMessage > 0) {
    bot.last_message_received = bot.messages[0].update_id;
  }
}

// Головний нескінченний цикл виконання програми мікроконтролера
void loop() {
  // Асинхронний диспетчер режимів індикації системного світлодіода
  if (sysLedInterval > 0) {
    if (millis() - lastSysLedBlink > sysLedInterval) {
      lastSysLedBlink = millis();
      sysLedState = !sysLedState;
      ledcWrite(LED_SYS_PIN, sysLedState ? 255 : 0);
    }
  } else {
    ledcWrite(LED_SYS_PIN, 255); 
  }

  // Сканування стану фізичної стінової кнопки виходу (блокується під час дії таймауту безпеки)
  if (isAccessAllowed && !isButtonCooldown && digitalRead(BUTTON_PIN) == LOW) {
    delay(50); // Апаратне вікно фільтрації брязкоту контактів кнопки
    if (digitalRead(BUTTON_PIN) == LOW) {
      Serial.println("[DEBUG] Натиснуто фізичну кнопку відкриття дверей.");
      
      openDoor(); // Виклик функції імпульсу реле. Кнопка почне миготіти тільки після закриття замка
      
      isButtonCooldown = true;
      cooldownStartTime = millis();
      while(digitalRead(BUTTON_PIN) == LOW) { delay(10); } // Очікуємо повного відпускання кнопки користувачем
    }
  }

  // Алгоритм генерації миготіння підсвітки кнопки під час діючого блокування (Cooldown)
  if (isButtonCooldown) {
    if (millis() - cooldownStartTime < COOLDOWN_DURATION) {
      if (millis() - lastBtnLedToggle > 250) {
        lastBtnLedToggle = millis();
        btnLedState = !btnLedState;
        digitalWrite(LED_BTN_PIN, btnLedState);
      }
    } else {
      isButtonCooldown = false;
      Serial.println("[DEBUG] Тайм-аут пристрою завершено. Замок та кнопка знову доступні.");
      if (isAccessAllowed) {
        digitalWrite(LED_BTN_PIN, HIGH); 
      } else {
        digitalWrite(LED_BTN_PIN, LOW);  
      }
    }
  }

  // Опитування та читання нових повідомлень Telegram (активне тільки при наявності лінку Ethernet)
  if (eth_connected) {
    static unsigned long lastBotCheck = 0;
    if (millis() - lastBotCheck > 1000) { // Перевірка виконується суворо один раз на секунду (без затримок)
      int newMessage = bot.getUpdates(-1);
      if (newMessage) {
        handleNewMessages();
      }
      lastBotCheck = millis();
    }
  }
}

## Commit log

2026-07-08 Add photo materials
2026-07-09 add 3d models
    [Bottom.stl, Top.stl]
